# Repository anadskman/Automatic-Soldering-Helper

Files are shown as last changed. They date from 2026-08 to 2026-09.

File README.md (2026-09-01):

# Automatic Soldering Helper



A small robot arm that can help hold wires, PCBs and other parts while I'm soldering.

I wanted to make something like a motorised helping hand that I can move around with buttons instead of having to keep adjusting normal helping hands every time.

I already had most of the motors and electronics so I decided to try make the arm mostly out of parts I already had.

## How It Works

The whole arm rotates around the base using a **28BYJ-48 stepper motor** and a **ULN2003 driver**.

The rest of the arm uses 4 small 9g servos:

- Shoulder
- Elbow
- Wrist
- Clamp

I originally planned on using a gear ratio for the base because I thought the stepper might struggle with the weight of the arm.

After printing most of the arm and seeing how light it actually was I decided to remove the whole gear ratio part and just attach the motor directly to the arm. This also makes the base way simpler and smaller.

## Testing

Before buying the final electronics I printed everything for the arm except the final motor base and connected it to an Arduino Uno just to confirm the idea would actually work.

I only have 3 potentiometers so for testing I used them to control the servos and switched between the wrist and clamp when needed.

Kinda surprisingly it worked pretty well.

There is a small bit of electrical noise making the servos vibrate but I'm adding a 1000uF capacitor to the final electronics which should help with that.

The Arduino is only being used for testing. The final version will use an ESP32.

## Clamp

I printed a small basic clamp for the first test just to make sure the servo could actually open and close something.

After that I redesigned it into a bigger clamp taking inspiration from some videos I saw on Instagram.

The bigger one should be much more useful for actually holding wires, connectors and small PCBs so I think I'll use that for the final version.

The clamp is controlled by another 9g servo.

## Controls

I wanted the final arm to use physical controls instead of needing a computer every time I want to move it.

I'm using:

- 3 potentiometers
- 6 momentary buttons

The potentiometers can be used to manually position the shoulder, elbow and wrist.

The buttons can then be used for things like:

- Saved positions
- Moving the base
- Opening and closing the clamp
- Home
- Changing modes

The ESP32 can save arm positions so I can move the arm somewhere useful and then return to that position later without manually adjusting everything again.

## Saved Positions

A saved position can store:

- Base position
- Shoulder angle
- Elbow angle
- Wrist angle
- Clamp position

This means I could have different positions for stuff like holding wires or holding a PCB.

The positions will be stored on the ESP32 so they don't disappear every time it loses power.

## Base

The base uses the 28BYJ-48 stepper motor I already had.

I originally designed a larger base with printed gears to increase the torque but after actually printing the arm it was much lighter than I expected.

Because of that I decided to remove the gears and just drive the rotating part directly from the stepper.

There will also be a limit switch so the arm can find its home position when it starts.

## Table Mount

For attaching the whole thing to my desk I'm going to reuse the clamp from my old helping hands.

It already works well for attaching stuff to the edge of a table so there isn't much point designing another clamp.

The helping hands clamp will just slot into a mount on the bottom of the arm.

## Electronics

The final controller will be an **ESP32 CH340C USB-C development board**.

The servos aren't going to be powered directly from the ESP32.

They will use the 5V power rail and all of the grounds will be connected together.

I'm also adding a 1000uF capacitor across the servo power to help with the small amount of electrical noise I noticed while testing.

The stepper motor will be controlled through its ULN2003 board.

## PCB

I don't really need a normal manufactured PCB for this project so I'm making a 3D printed one instead.

The PCB will basically have slots and paths where I can insert the wires to keep everything organised.

I redesigned the PCB after working out the final electronics and made sure to export the traces in the STEP this time because I forgot to last time and ended up drawing them by hand in Fusion.

The ESP32 and other electronics can then mount onto this inside the case.

## Firmware

The final firmware will run on the ESP32.

Instead of using GRBL I decided to make the position system specifically for the arm since only the base uses a stepper and everything else uses servos.

The firmware will handle:

- Manual movement
- Servo control
- Stepper control
- Clamp control
- Saved positions
- Base homing
- Smooth movement
- Physical buttons
- Potentiometer controls

This should make it pretty easy to use while I'm actually soldering instead of having to control it from my computer.

## BOM

| Item | Qty | Status | Price | Notes |
| --- | ---: | --- | ---: | --- |
| [ESP32-CH340C-Type-C](https://www.aliexpress.com/item/1005008723399881.html) | 1 | Buy | $5.03 | Main controller |
| [1000uF 50V Electrolytic Capacitors](https://www.aliexpress.com/item/1005005920255833.html) | 5 | Buy | $2.22 | Servo power smoothing |
| [M2 Hex Socket Button Head Screw Kit](https://www.aliexpress.com/item/1005007278965396.html) | 1 | Buy | $6.99 | Arm assembly |
| [DS228/DS428 12mm Green Momentary Pushbuttons](https://www.aliexpress.com/item/1005008558481882.html) | 6 | Buy | $3.25 | Physical controls |
| 28BYJ-48 5V Stepper Motor | 1 | Owned | $0.00 | Rotates the arm |
| ULN2003 Stepper Driver Board | 1 | Owned | $0.00 | Drives the stepper |
| 9g Servo | 4 | Owned | $0.00 | Shoulder, elbow, wrist and clamp |
| 10k Potentiometer | 3 | Owned | $0.00 | Manual arm controls |
| Limit Switch | 1 | Owned | $0.00 | Base homing |
| 10k Resistor | 1 | Owned | $0.00 | Limit switch pull-up |

### Order Cost

| | Cost |
| --- | ---: |
| Subtotal | $17.56 |
| Savings | -$0.19 |
| Shipping | $0.00 |
| Estimated import charges | $16.93 |
| **Total** | **$34.30** |

## Current Progress

So far I've:

- Designed the arm in CAD
- Printed most of the arm
- Designed the clamp
- Tested the servos with an Arduino Uno
- Confirmed the arm can actually move
- Simplified the rotating base
- Planned the ESP32 controls
- Planned the saved position system
- Designed the 3D printed PCB
- Worked out the final BOM

The main thing now is getting the final parts and putting everything together properly.

## Images

| Schematic | PCB | Case |
| --- | --- | --- |
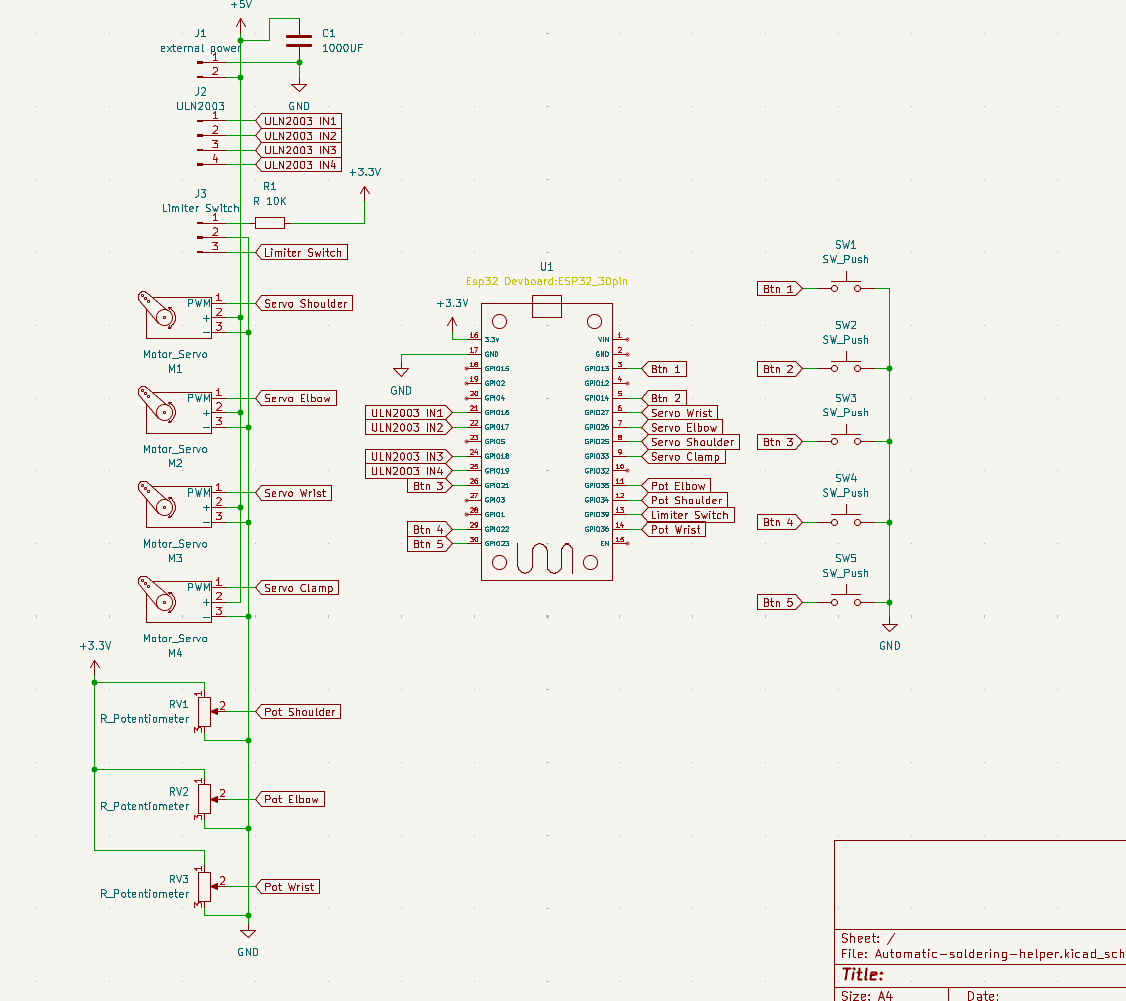
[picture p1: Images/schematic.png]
Schematic
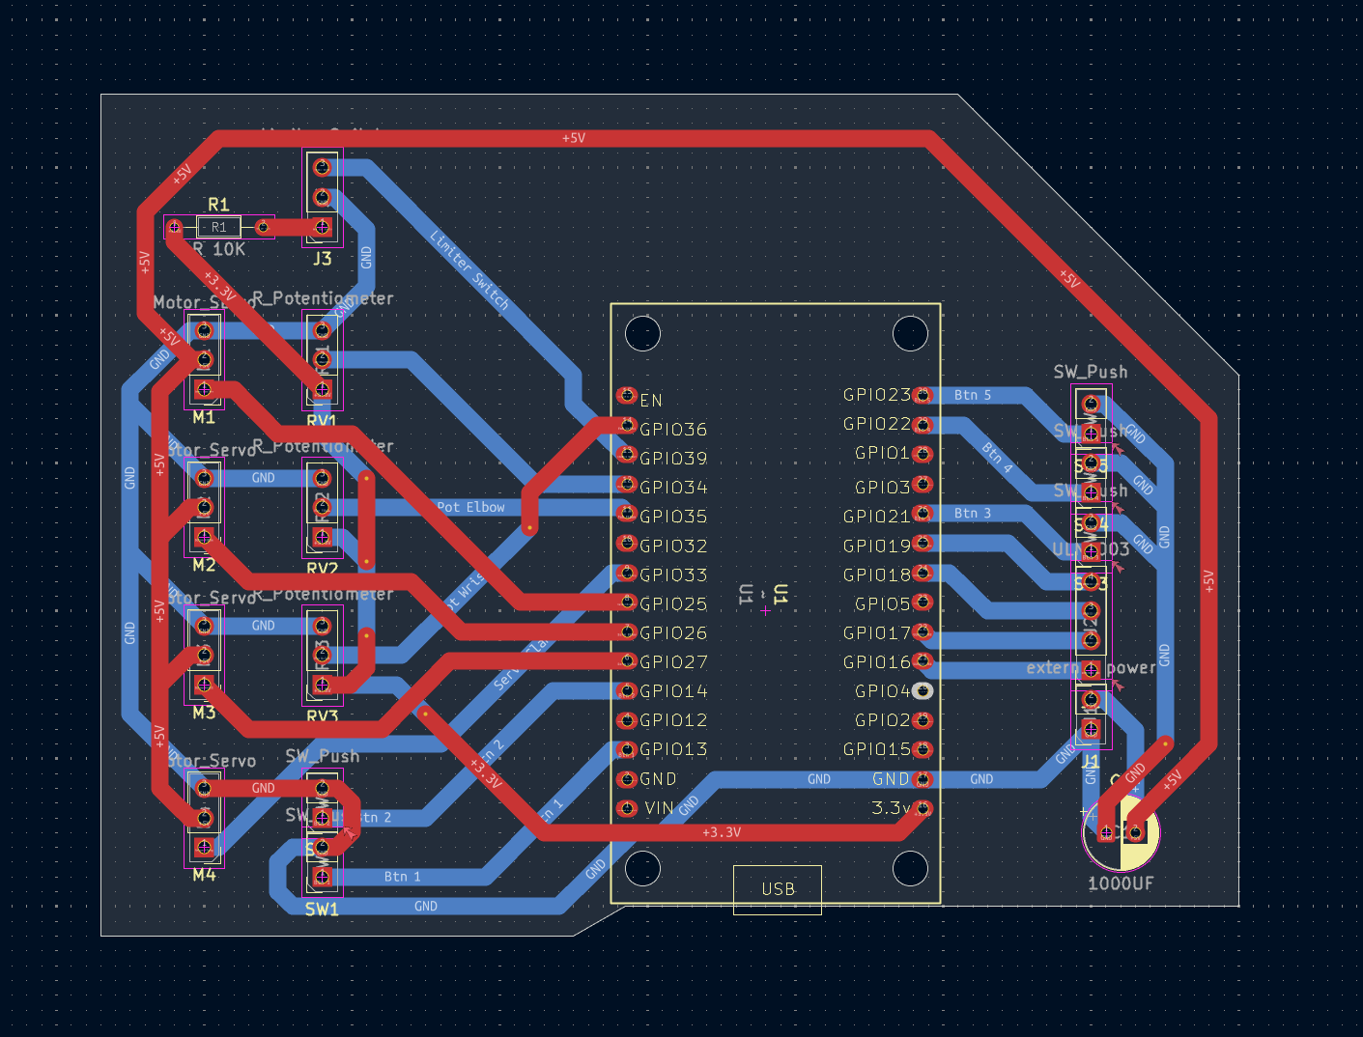
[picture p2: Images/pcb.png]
PCB
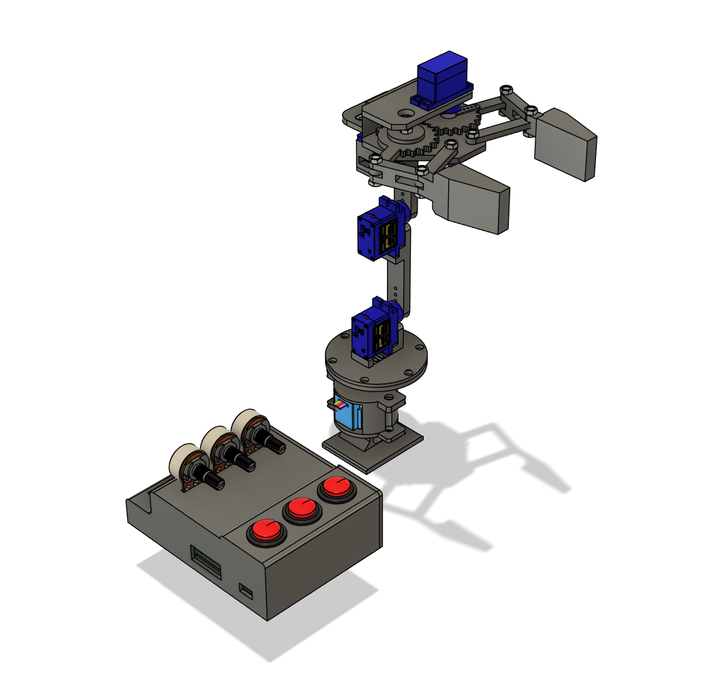
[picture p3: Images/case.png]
Case
|  |  |  |

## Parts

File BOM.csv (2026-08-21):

Item | Quantity | Status | Price USD | Notes | URL
ESP32-CH340C-Type-C | 1 | Buy | 5.03 | Main controller | https://www.aliexpress.com/item/1005008723399881.html
1000uF 50V Electrolytic Capacitors | 5 | Buy | 2.22 | Servo power smoothing | https://www.aliexpress.com/item/1005005920255833.html
M2 Hex Socket Button Head Screw Kit | 1 | Buy | 6.99 | Arm assembly | https://www.aliexpress.com/item/1005007278965396.html
DS228/DS428 12mm Green Momentary Pushbuttons | 6 | Buy | 3.25 | Physical controls | https://www.aliexpress.com/item/1005008558481882.html
28BYJ-48 5V Stepper Motor | 1 | Owned | 0.00 | Rotates the base
ULN2003 Stepper Driver Board | 1 | Owned | 0.00 | Drives the 28BYJ-48
9g Servo | 4 | Owned | 0.00 | Shoulder elbow wrist and clamp
10k Potentiometer | 3 | Owned | 0.00 | Manual arm controls
Limit Switch | 1 | Owned | 0.00 | Base homing
10k Resistor | 1 | Owned | 0.00 | Limit switch pull-up
Order Import Charges | 1 | Buy | 16.93 | Estimated import charges
TOTAL |  |  | 34.30 | Final checkout total

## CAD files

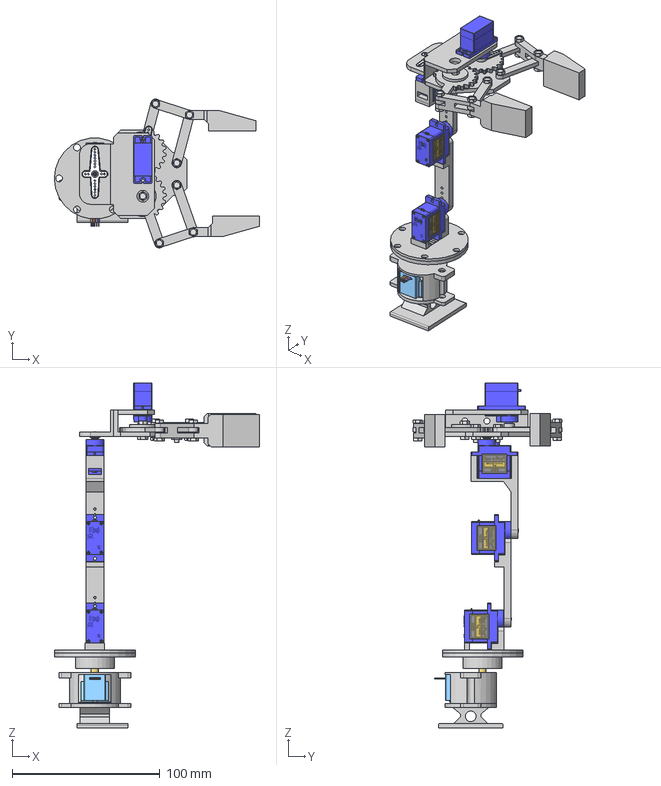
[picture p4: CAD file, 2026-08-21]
CAD/Fully Assembled.step
139.2 x 101.0 x 233.8 mm
Bottom
Sides
Top
28BYJ-48_Stepper
Tower Pro - Micro Servo 9g - SG90.1 x 3
Tower Pro - Micro Servo 9g - SG90.1 (1) x 3
Tower Pro - Micro Servo 9g - SG90.1 (2) x 3
Tower Pro - Micro Servo 9g - SG90.1 (3) x 3
Tower Pro - Micro Servo 9g - SG90.1 (4) x 3
Tower Pro - Micro Servo 9g - SG90.1 (5) x 3
Tower Pro - Micro Servo 9g - SG90.1 (6) x 3
Tower Pro - Micro Servo 9g - SG90.1 (7) x 3
Tower Pro - Micro Servo 9g - SG90.1 (8) x 3
Tower Pro - Micro Servo 9g - SG90.1 (9) x 3
Tower Pro - Micro Servo 9g - SG90.1 (10) x 3
Tower Pro - Micro Servo 9g - SG90.1 (11) x 3
Tower Pro - Micro Servo 9g - SG90.1 (12) x 3
SG90 - Micro Servo 9g - Tower Pro.2 x 2
SG90 - Micro Servo 9g - Tower Pro.6 x 3
SG90 - Micro Servo 9g - Tower Pro.4
gear
gripper x 2
tuas x 2
microservoSG90
gear 2.1
servo horn 1 v2
base 2.0 upload
Gear Ring
AS 1427 - M3 x 10 x 3
AS 1427 - M3 x 12 x 4
AS 1112 - M3,5 x 7
ISO 7046-1 - M1,6 x 8 - 4.8 - H

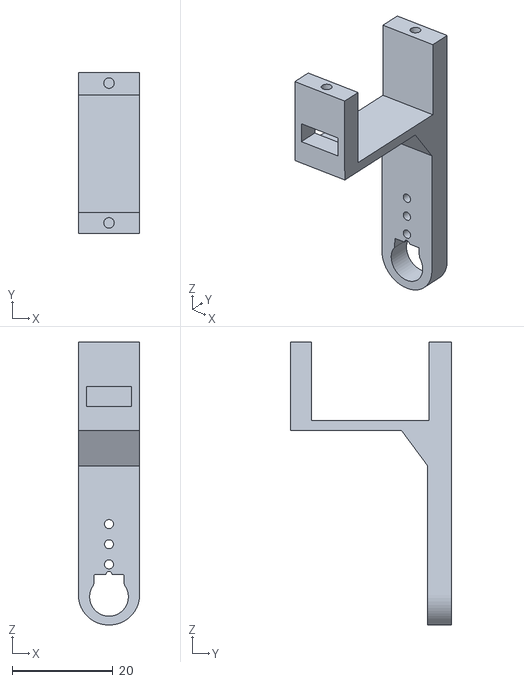
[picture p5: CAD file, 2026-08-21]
CAD/Arm/Arm Wrist.stl
12.2 x 32.1 x 56.2

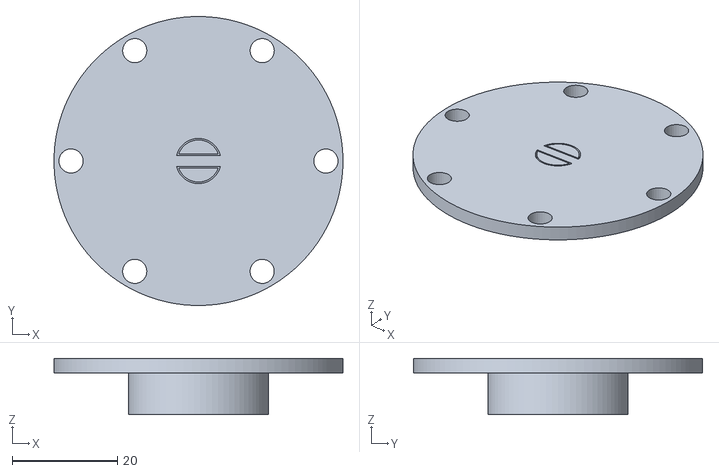
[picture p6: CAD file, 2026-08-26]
CAD/Base/Arm Mount.stl
55.0 x 55.0 x 10.7

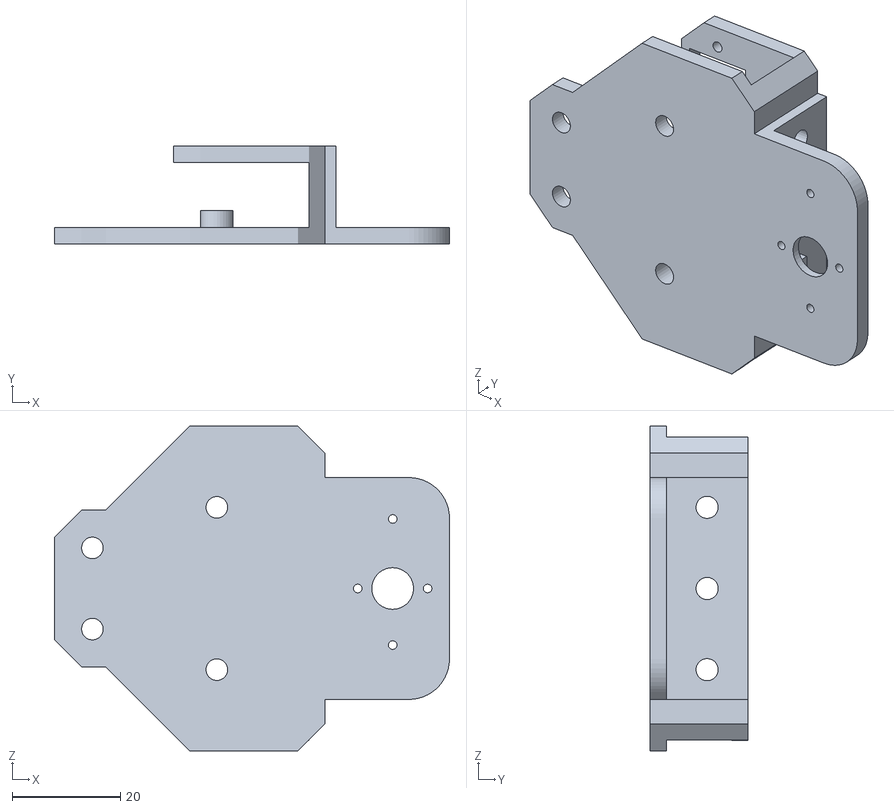
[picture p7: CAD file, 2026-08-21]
CAD/Clamp/Clamp Base.stl
73.0 x 18.1 x 60.0

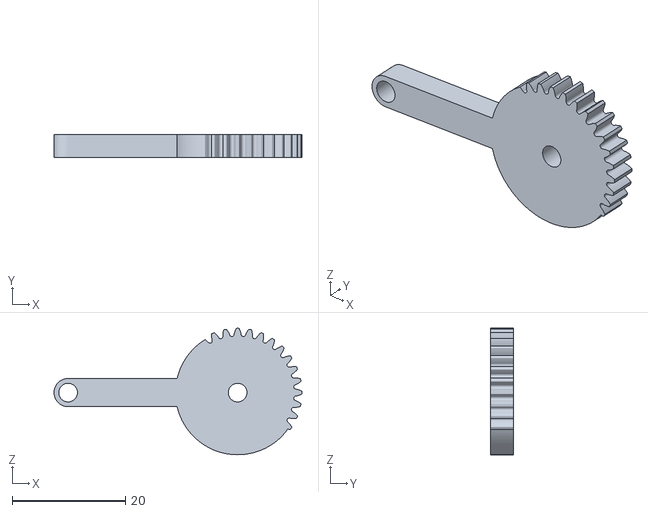
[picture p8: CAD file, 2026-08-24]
CAD/Clamp/v4/gear_left.stl
43.9 x 4.00 x 22.4

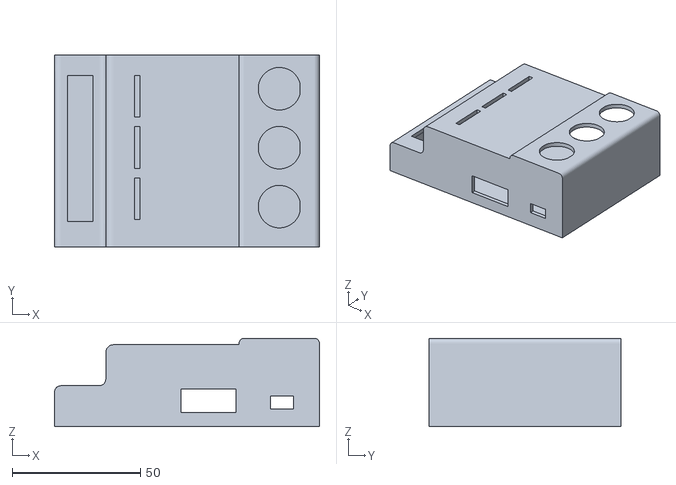
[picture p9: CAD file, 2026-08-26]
CAD/PCB/PCB Case.stl
103.4 x 75.0 x 34.5

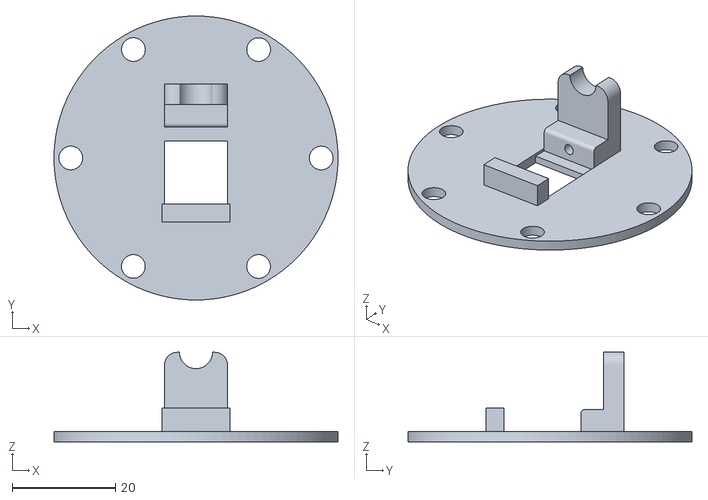
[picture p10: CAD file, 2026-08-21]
CAD/Arm/Arm Shoulder.stl
55.0 x 55.0 x 17.4

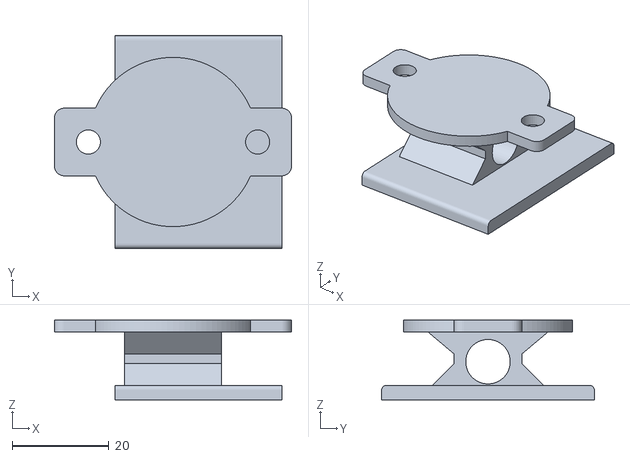
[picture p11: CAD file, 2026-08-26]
CAD/Base/Motor Bottom.stl
49.0 x 44.0 x 16.5

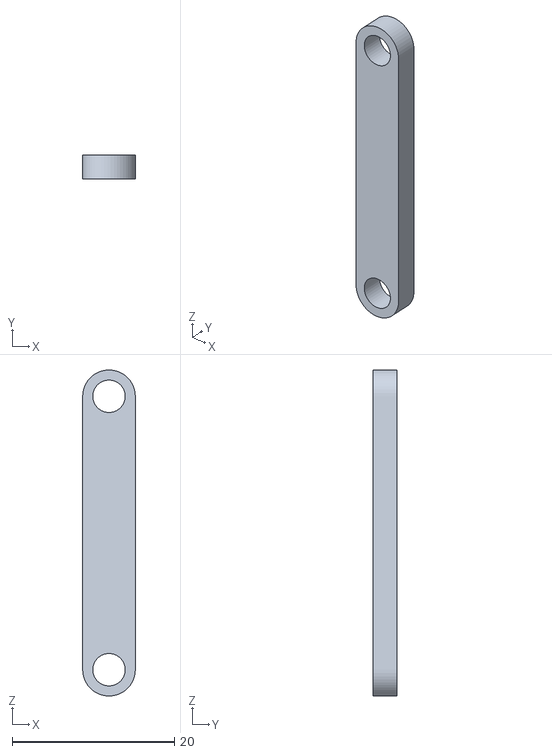
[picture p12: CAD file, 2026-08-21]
CAD/Clamp/Right Attachment.stl
6.50 x 3.00 x 40.2

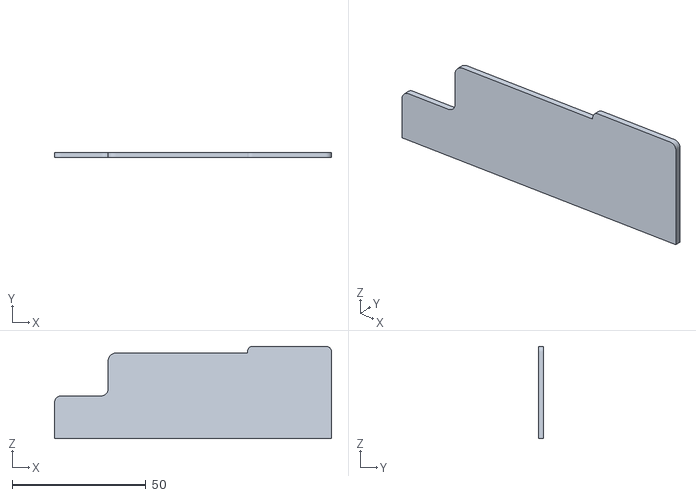
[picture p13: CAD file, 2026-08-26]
CAD/PCB/PCB Side.stl
103.4 x 2.00 x 34.5

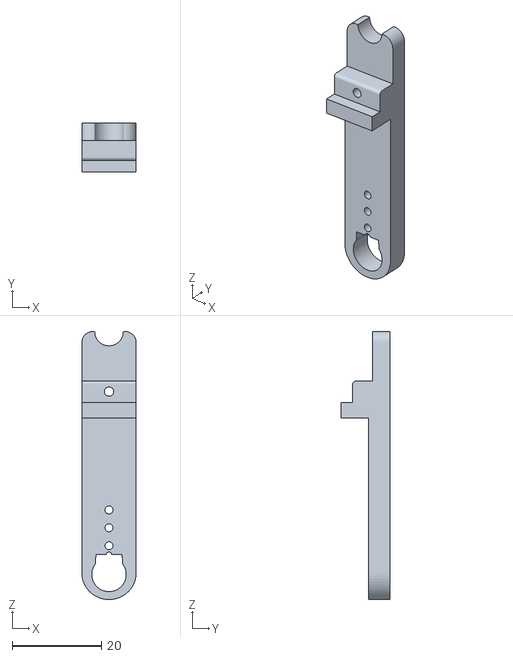
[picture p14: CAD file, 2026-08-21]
CAD/Arm/Arm Elbow.stl
12.2 x 11.0 x 60.0

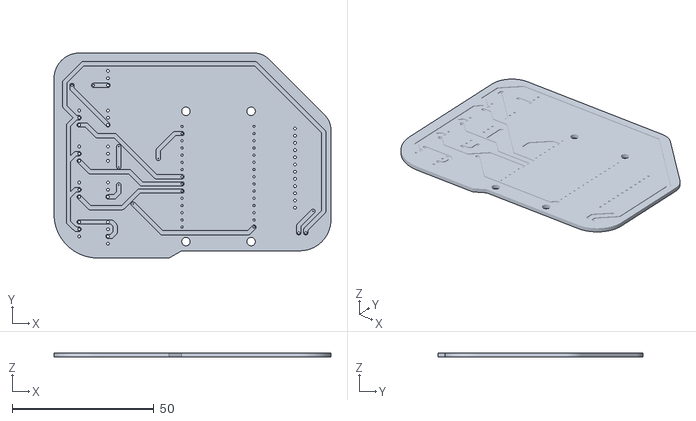
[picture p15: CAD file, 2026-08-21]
CAD/Base/Automatic Soldering Helper_PCB.stl
97.8 x 72.4 x 1.51

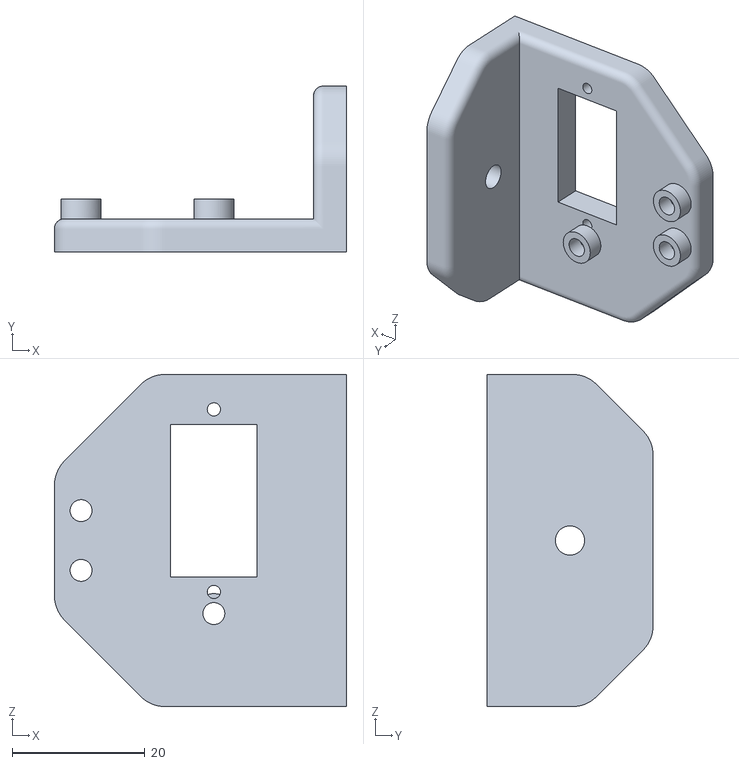
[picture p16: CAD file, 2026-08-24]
CAD/Clamp/v4/base_plate.stl
44.0 x 25.0 x 50.0

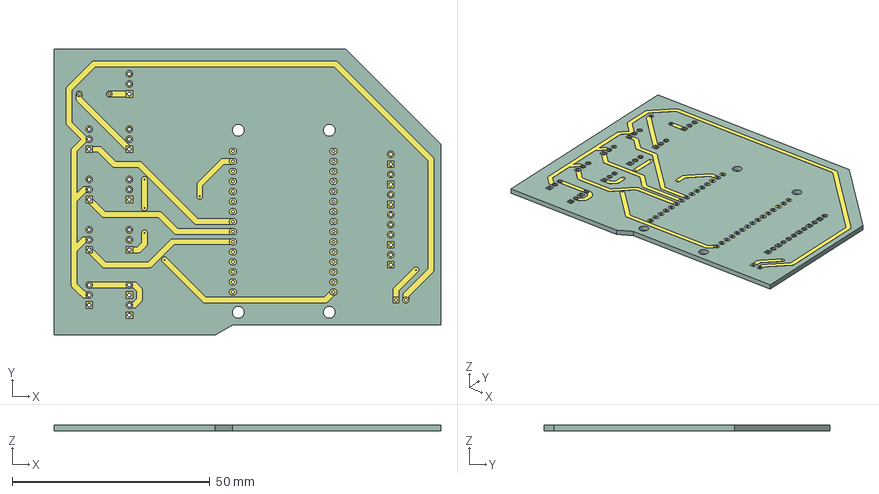
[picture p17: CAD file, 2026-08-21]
CAD/PCB/Automatic-Soldering-Helper-PCB2.step
97.8 x 72.4 x 1.59 mm
Automatic-soldering-helper_copper
Automatic-soldering-helper_pad
Automatic-soldering-helper_via
Automatic-soldering-helper_PCB

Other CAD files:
CAD/Clamp/v4/gear_right.stl
CAD/Base/Motor Case.stl
CAD/Clamp/Left Hand.stl
CAD/Automatic Soldering Helper.f3z
CAD/Clamp/Drive Gear.stl
CAD/Clamp/Driven Gear.stl
CAD/Clamp/Right Hand.stl
CAD/Clamp/v4/arm_left.stl
CAD/Clamp/v4/arm_right.stl
CAD/Clamp/v4/jaw_left.stl
CAD/Clamp/v4/jaw_right.stl

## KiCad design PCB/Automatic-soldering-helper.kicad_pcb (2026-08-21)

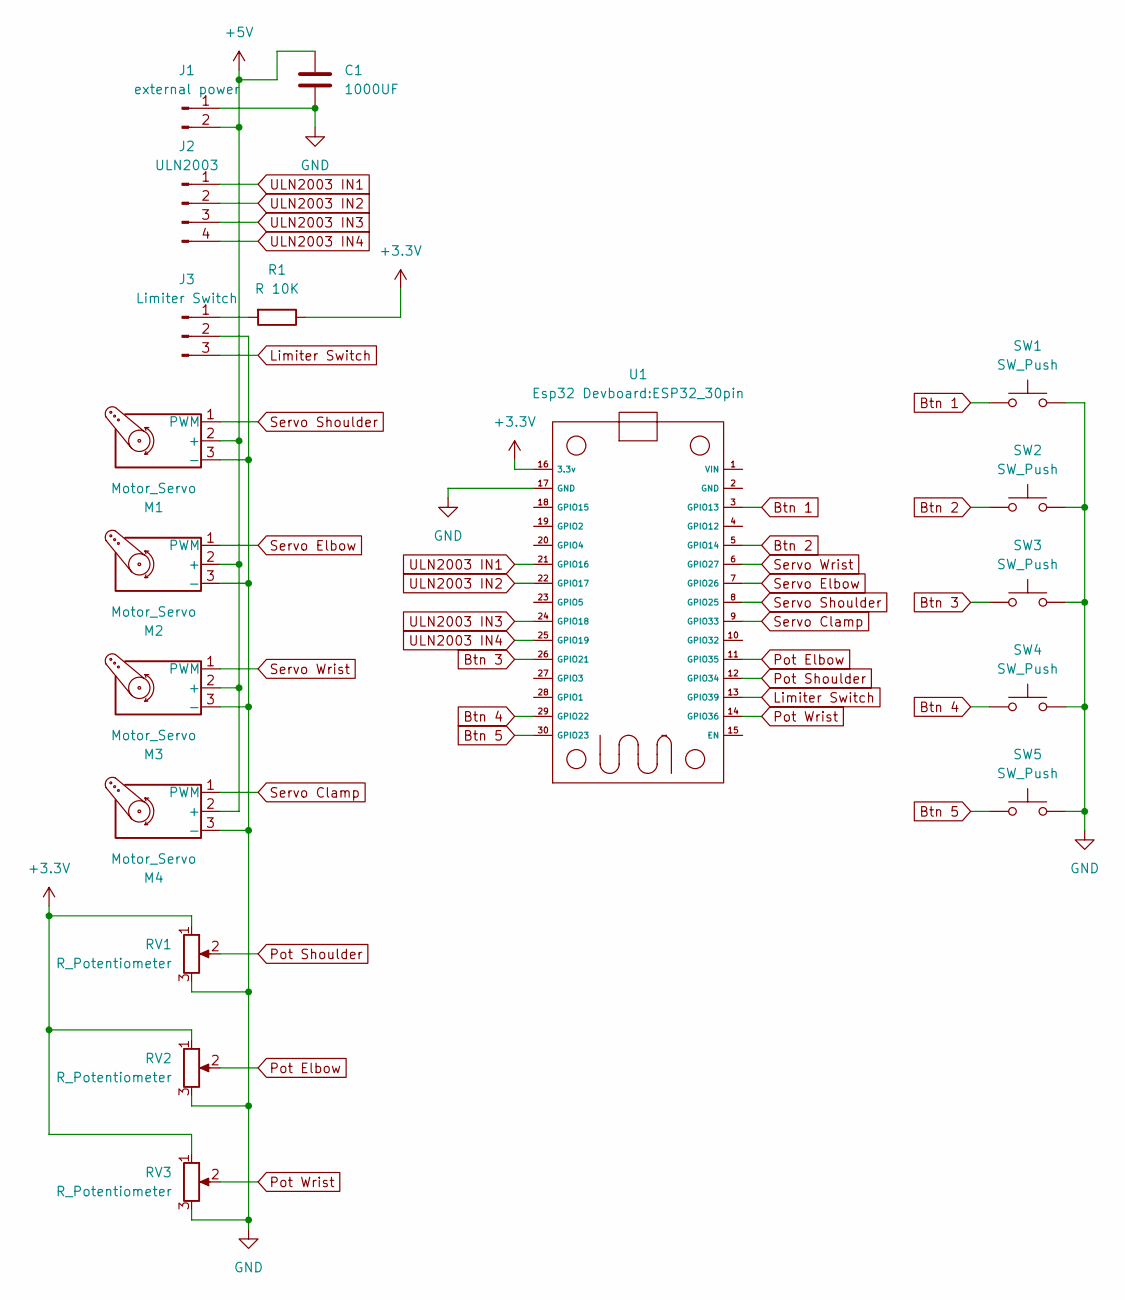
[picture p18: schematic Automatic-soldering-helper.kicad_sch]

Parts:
C1: 1000UF; CP_Radial_D6.3mm_P2.50mm
J1: external power; PinSocket_1x02_P2.54mm_Vertical
J2: ULN2003; PinSocket_1x04_P2.54mm_Vertical
J3: Limiter Switch; PinSocket_1x03_P2.54mm_Vertical
M1, M2, M3, M4: Motor_Servo; PinHeader_1x03_P2.54mm_Vertical
R1: R 10K; R_Axial_DIN0204_L3.6mm_D1.6mm_P7.62mm_Horizontal
RV1, RV2, RV3: R_Potentiometer; PinSocket_1x03_P2.54mm_Vertical
SW1, SW2, SW3, SW4, SW5: SW_Push; PinSocket_1x02_P2.54mm_Vertical
U1: ESP32_30pin

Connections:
+3.3V: R1.1, RV1.1, RV2.1, RV3.1, U1.16 (3.3v)
+5V: C1.2, J1.2, M1.2 (+), M2.2 (+), M3.2 (+), M4.2 (+)
Btn 1: SW1.1, U1.3 (GPIO13)
Btn 2: SW2.1, U1.5 (GPIO14)
Btn 3: SW3.1, U1.26 (GPIO21)
Btn 4: SW4.1, U1.29 (GPIO22)
Btn 5: SW5.1, U1.30 (GPIO23)
GND: C1.1, J1.1, J3.2, M1.3 (-), M2.3 (-), M3.3 (-), M4.3 (-), RV1.3, RV2.3, RV3.3, SW1.2, SW2.2, SW3.2, SW4.2, SW5.2, U1.17 (GND)
Limiter Switch: J3.3, U1.13 (GPIO39)
unnamed: J3.1, R1.2
Pot Elbow: RV2.2, U1.11 (GPIO35)
Pot Shoulder: RV1.2, U1.12 (GPIO34)
Pot Wrist: RV3.2, U1.14 (GPIO36)
Servo Clamp: M4.1 (PWM), U1.9 (GPIO33)
Servo Elbow: M2.1 (PWM), U1.7 (GPIO26)
Servo Shoulder: M1.1 (PWM), U1.8 (GPIO25)
Servo Wrist: M3.1 (PWM), U1.6 (GPIO27)
ULN2003 IN1: J2.1, U1.21 (GPIO16)
ULN2003 IN2: J2.2, U1.22 (GPIO17)
ULN2003 IN3: J2.3, U1.24 (GPIO18)
ULN2003 IN4: J2.4, U1.25 (GPIO19)

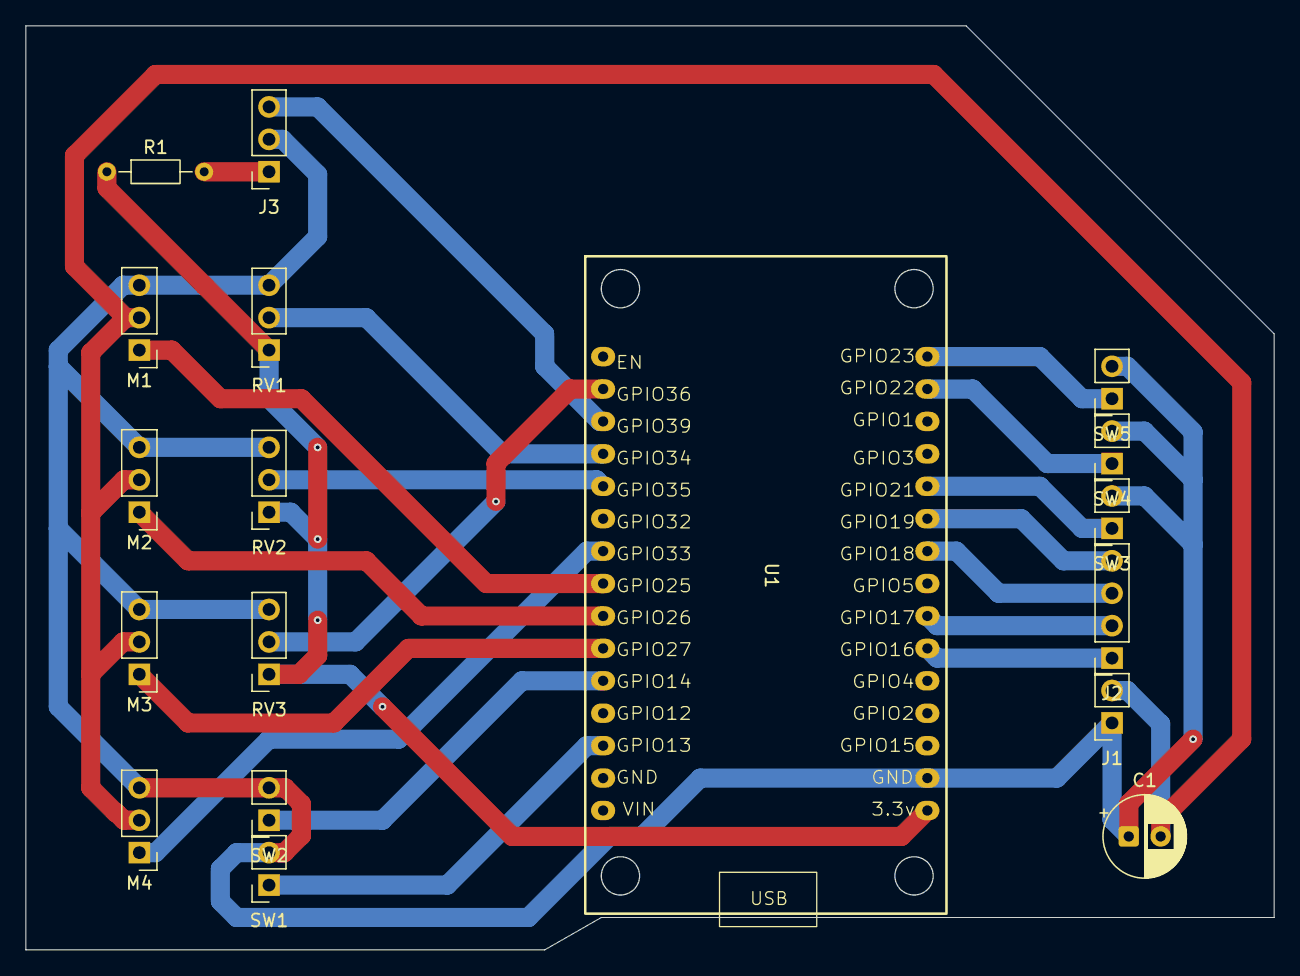
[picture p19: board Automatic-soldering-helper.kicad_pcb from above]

Board: 2 copper layers, 97.8 x 72.4 mm, 18 parts (0 on the bottom side), 21 nets.

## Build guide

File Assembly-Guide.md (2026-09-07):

# Quick Assembly guide.

adding this as request because of so many little parts

## Arm

Probably the easiest part, where you see those small holes you just screw in the servos.
using the screws that come with the servos.
to attach the horn to next piece you put it in place connect to the servo and put the horn screw in and one(or two, its up to you) m1 i believe it is.

## Base

for the motor its pretty simple you just place it in and then screw it all together.

the arm mount just uses m4 screws to connected to the shoulder

## Clamp

id just ignore the first clamp and just focus on v4(prints quicker and looks nicer)

the arms just screw into the base and jaw, then the gears go into the base and jaws.

Please note when attaching the servo to put the horn side away from the other gear so they can connect properly

## PCB

lastly the pcb, once its printed you should be able to place the wires into the gaps.
for the case you can leave the side off, or just superglue it there.

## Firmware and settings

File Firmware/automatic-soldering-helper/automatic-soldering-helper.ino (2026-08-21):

// =====================================================
// AUTOMATIC SOLDERING HELPER v1
// =====================================================

#include <ESP32Servo.h>
#include <Preferences.h>

// ---------------- SERVOS ----------------

#define PIN_SHOULDER 25
#define PIN_ELBOW    26
#define PIN_WRIST    27
#define PIN_CLAMP    33

Servo shoulderServo;
Servo elbowServo;
Servo wristServo;
Servo clampServo;

// ---------------- POTS ----------------

#define POT_SHOULDER 34
#define POT_ELBOW    35
#define POT_WRIST    36

// ---------------- STEPPER ----------------

#define STEP_IN1 16
#define STEP_IN2 17
#define STEP_IN3 18
#define STEP_IN4 19

// ---------------- HOME ----------------

#define HOME_SWITCH 39

// External 10k pull-up:
// GPIO39 -> 10k -> 3.3V
// GPIO39 -> switch -> GND

// ---------------- BUTTONS ----------------

#define BTN_1 13
#define BTN_2 14
#define BTN_3 21
#define BTN_4 22
#define BTN_5 23

// ---------------- SERVO LIMITS ----------------

int SHOULDER_MIN = 30;
int SHOULDER_MAX = 150;

int ELBOW_MIN = 25;
int ELBOW_MAX = 155;

int WRIST_MIN = 20;
int WRIST_MAX = 160;

int CLAMP_OPEN = 45;
int CLAMP_CLOSED = 125;

// ---------------- HOME POSITION ----------------

int HOME_SHOULDER = 70;
int HOME_ELBOW = 120;
int HOME_WRIST = 90;

// ---------------- RETRACT POSITION ----------------

int RETRACT_SHOULDER = 55;
int RETRACT_ELBOW = 145;
int RETRACT_WRIST = 90;

// ---------------- CURRENT POSITION ----------------

int shoulderCurrent = HOME_SHOULDER;
int elbowCurrent = HOME_ELBOW;
int wristCurrent = HOME_WRIST;
int clampCurrent = CLAMP_OPEN;

// ---------------- TARGET POSITION ----------------

int shoulderTarget = HOME_SHOULDER;
int elbowTarget = HOME_ELBOW;
int wristTarget = HOME_WRIST;
int clampTarget = CLAMP_OPEN;

bool clampClosed = false;

// STEPPER

const byte stepSequence[8][4] = {
  {1,0,0,0},
  {1,1,0,0},
  {0,1,0,0},
  {0,1,1,0},
  {0,0,1,0},
  {0,0,1,1},
  {0,0,0,1},
  {1,0,0,1}
};

int stepIndex = 0;

long baseCurrent = 0;
long baseTarget = 0;

const long BASE_MIN = 0;
const long BASE_MAX = 4096;

unsigned long lastStepperMicros = 0;
const unsigned long STEPPER_SPEED = 1200;

// PRESETS

struct ArmPosition {
  long base;
  int shoulder;
  int elbow;
  int wrist;
  int clamp;
};

ArmPosition presets[3];

bool presetValid[3] = {
  false,
  false,
  false
};

Preferences prefs;

int saveSlot = 0;

// BUTTON SYSTEM

const int buttonPins[5] = {
  BTN_1,
  BTN_2,
  BTN_3,
  BTN_4,
  BTN_5
};

bool buttonState[5];
bool lastButtonState[5];

unsigned long pressStart[5];

const unsigned long HOLD_TIME = 1500;

// MODE

bool teachMode = false;

// TIMERS

unsigned long lastServoUpdate = 0;
unsigned long lastPotUpdate = 0;
unsigned long lastBaseJog = 0;

const int SERVO_INTERVAL = 15;
const int POT_INTERVAL = 30;

void setup() {

  Serial.begin(115200);

  // Servo setup

  shoulderServo.attach(PIN_SHOULDER, 500, 2400);
  elbowServo.attach(PIN_ELBOW, 500, 2400);
  wristServo.attach(PIN_WRIST, 500, 2400);
  clampServo.attach(PIN_CLAMP, 500, 2400);

  shoulderServo.write(shoulderCurrent);
  elbowServo.write(elbowCurrent);
  wristServo.write(wristCurrent);
  clampServo.write(clampCurrent);

  // Stepper pins

  pinMode(STEP_IN1, OUTPUT);
  pinMode(STEP_IN2, OUTPUT);
  pinMode(STEP_IN3, OUTPUT);
  pinMode(STEP_IN4, OUTPUT);

  // Buttons

  for (int i = 0; i < 5; i++) {

    pinMode(buttonPins[i], INPUT_PULLUP);

    buttonState[i] = HIGH;
    lastButtonState[i] = HIGH;
  }

  // Home sensor

  pinMode(HOME_SWITCH, INPUT);

  // Preferences storage

  prefs.begin("solderArm", false);

  loadPresets();

  delay(500);

  Serial.println();
  Serial.println("Automatic Soldering Helper");

  homeBase();

  Serial.println("Ready");
}


void loop() {

  readButtons();

  if (teachMode) {
    updateTeachMode();
  }

  updateServos();
  updateStepper();
}

// SMOOTH SERVO MOVEMENT

int moveOneDegree(int current, int target) {

  if (current < target) {
    return current + 1;
  }

  if (current > target) {
    return current - 1;
  }

  return current;
}

void updateServos() {

  if (millis() - lastServoUpdate < SERVO_INTERVAL) {
    return;
  }

  lastServoUpdate = millis();

  shoulderCurrent =
    moveOneDegree(shoulderCurrent, shoulderTarget);

  elbowCurrent =
    moveOneDegree(elbowCurrent, elbowTarget);

  wristCurrent =
    moveOneDegree(wristCurrent, wristTarget);

  clampCurrent =
    moveOneDegree(clampCurrent, clampTarget);

  shoulderServo.write(shoulderCurrent);
  elbowServo.write(elbowCurrent);
  wristServo.write(wristCurrent);
  clampServo.write(clampCurrent);
}

// STEPPER

void setStepperPhase(int index) {

  digitalWrite(STEP_IN1, stepSequence[index][0]);
  digitalWrite(STEP_IN2, stepSequence[index][1]);
  digitalWrite(STEP_IN3, stepSequence[index][2]);
  digitalWrite(STEP_IN4, stepSequence[index][3]);
}

void stepMotor(int direction) {

  stepIndex += direction;

  if (stepIndex > 7) {
    stepIndex = 0;
  }

  if (stepIndex < 0) {
    stepIndex = 7;
  }

  setStepperPhase(stepIndex);
}

void updateStepper() {

  if (baseCurrent == baseTarget) {
    return;
  }

  if (micros() - lastStepperMicros < STEPPER_SPEED) {
    return;
  }

  lastStepperMicros = micros();

  if (baseCurrent < baseTarget) {

    stepMotor(1);

    baseCurrent++;

  } else {

    stepMotor(-1);

    baseCurrent--;
  }
}

// HOMING

void homeBase() {

  Serial.println("Homing base...");

  long attempts = 0;

  while (
    digitalRead(HOME_SWITCH) == HIGH &&
    attempts < 5000
  ) {

    stepMotor(-1);

    delayMicroseconds(1800);

    attempts++;
  }

  if (digitalRead(HOME_SWITCH) == LOW) {

    baseCurrent = 0;
    baseTarget = 0;

    Serial.println("Home found");

  } else {

    Serial.println("Home switch not found");

    baseCurrent = 0;
    baseTarget = 0;
  }
}

// BUTTONS

void readButtons() {

  for (int i = 0; i < 5; i++) {

    bool state = digitalRead(buttonPins[i]);

    if (
      state == LOW &&
      lastButtonState[i] == HIGH
    ) {

      pressStart[i] = millis();
    }

    if (
      state == HIGH &&
      lastButtonState[i] == LOW
    ) {

      unsigned long held =
        millis() - pressStart[i];

      handleButton(i, held);
    }

    lastButtonState[i] = state;
  }
}

// BUTTON ACTIONS

void handleButton(int button, unsigned long held) {

  // BUTTON 1

  if (button == 0) {

    if (teachMode) {

      // Base left handled elsewhere

    } else {

      runPreset(0);
    }
  }

  // BUTTON 2

  if (button == 1) {

    if (teachMode) {

      // Base right handled elsewhere

    } else {

      runPreset(1);
    }
  }

  // BUTTON 3

  if (button == 2) {

    if (teachMode && held >= HOLD_TIME) {

      savePreset(saveSlot);

      saveSlot++;

      if (saveSlot > 2) {
        saveSlot = 0;
      }

    } else if (!teachMode) {

      runPreset(2);
    }
  }

  // BUTTON 4

  if (button == 3) {

    if (held >= HOLD_TIME) {

      teachMode = !teachMode;

      Serial.print("Teach mode: ");

      if (teachMode) {
        Serial.println("ON");
      } else {
        Serial.println("OFF");
      }

    } else {

      if (!teachMode) {
        goHome();
      }
    }
  }

  // BUTTON 5

  if (button == 4) {

    if (held >= HOLD_TIME) {

      emergencyRetract();

    } else {

      toggleClamp();
    }
  }
}

// TEACH MODE

void updateTeachMode() {

  // Pots

  if (millis() - lastPotUpdate >= POT_INTERVAL) {

    lastPotUpdate = millis();

    int s = analogRead(POT_SHOULDER);
    int e = analogRead(POT_ELBOW);
    int w = analogRead(POT_WRIST);

    shoulderTarget = map(
      s,
      0,
      4095,
      SHOULDER_MIN,
      SHOULDER_MAX
    );

    elbowTarget = map(
      e,
      0,
      4095,
      ELBOW_MIN,
      ELBOW_MAX
    );

    wristTarget = map(
      w,
      0,
      4095,
      WRIST_MIN,
      WRIST_MAX
    );
  }

  // Base jogging

  if (millis() - lastBaseJog > 25) {

    lastBaseJog = millis();

    // Button 1

    if (digitalRead(BTN_1) == LOW) {

      baseTarget -= 6;

      if (baseTarget < BASE_MIN) {
        baseTarget = BASE_MIN;
      }
    }

    // Button 2

    if (digitalRead(BTN_2) == LOW) {

      baseTarget += 6;

      if (baseTarget > BASE_MAX) {
        baseTarget = BASE_MAX;
      }
    }
  }
}

// CLAMP

void toggleClamp() {

  clampClosed = !clampClosed;

  if (clampClosed) {

    clampTarget = CLAMP_CLOSED;

    Serial.println("Clamp closed");

  } else {

    clampTarget = CLAMP_OPEN;

    Serial.println("Clamp open");
  }
}

// PRESETS

void savePreset(int slot) {

  presets[slot].base = baseCurrent;
  presets[slot].shoulder = shoulderCurrent;
  presets[slot].elbow = elbowCurrent;
  presets[slot].wrist = wristCurrent;
  presets[slot].clamp = clampCurrent;

  String key =
    "preset" + String(slot);

  prefs.putBytes(
    key.c_str(),
    &presets[slot],
    sizeof(ArmPosition)
  );

  String validKey =
    "valid" + String(slot);

  prefs.putBool(
    validKey.c_str(),
    true
  );

  presetValid[slot] = true;

  Serial.print("Saved preset ");
  Serial.println(slot + 1);
}

void loadPresets() {

  for (int i = 0; i < 3; i++) {

    String key =
      "preset" + String(i);

    String validKey =
      "valid" + String(i);

    presetValid[i] =
      prefs.getBool(
        validKey.c_str(),
        false
      );

    if (presetValid[i]) {

      prefs.getBytes(
        key.c_str(),
        &presets[i],
        sizeof(ArmPosition)
      );
    }
  }
}

void runPreset(int slot) {

  if (!presetValid[slot]) {

    Serial.print("Preset ");
    Serial.print(slot + 1);
    Serial.println(" not saved");

    return;
  }

  teachMode = false;

  baseTarget =
    constrain(
      presets[slot].base,
      BASE_MIN,
      BASE_MAX
    );

  shoulderTarget =
    constrain(
      presets[slot].shoulder,
      SHOULDER_MIN,
      SHOULDER_MAX
    );

  elbowTarget =
    constrain(
      presets[slot].elbow,
      ELBOW_MIN,
      ELBOW_MAX
    );

  wristTarget =
    constrain(
      presets[slot].wrist,
      WRIST_MIN,
      WRIST_MAX
    );

  clampTarget =
    presets[slot].clamp;

  Serial.print("Preset ");
  Serial.println(slot + 1);
}

// HOME

void goHome() {

  Serial.println("Going home");

  teachMode = false;

  clampTarget = CLAMP_OPEN;

  wristTarget = HOME_WRIST;

  elbowTarget = HOME_ELBOW;

  shoulderTarget = HOME_SHOULDER;

  baseTarget = 0;

  clampClosed = false;
}

// EMERGENCY RETRACT

void emergencyRetract() {

  Serial.println("EMERGENCY RETRACT");

  teachMode = false;

  clampTarget = CLAMP_OPEN;

  wristTarget = RETRACT_WRIST;

  elbowTarget = RETRACT_ELBOW;

  shoulderTarget = RETRACT_SHOULDER;

  baseTarget = 0;

  clampClosed = false;
}

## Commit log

2026-08-16 Add project journal for automatic soldering helper
    Document project idea and detailed plans for an automatic soldering helper robot arm, including features, controls, parts, and next steps.
2026-08-21 Pushed all Files
    [Arm Elbow.stl, Arm Mount.stl, Arm Shoulder.stl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]
2026-08-21 Enhance README with project details and progress
    Expanded the README to include detailed project description, functionality, components, and current progress.
2026-08-24 clamp files
    [arm_left.stl, arm_right.stl, base_plate.stl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]
2026-08-26 Hot fix
    [Arm Mount.stl, Motor Bottom.stl, PCB Case.stl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]
2026-08-26 Update Case image link in README
    Updated the image link for the Case in the README.
2026-09-01 added gerber and moved pcb file
    [Automatic-Soldering-Helper-PCB2.step]
